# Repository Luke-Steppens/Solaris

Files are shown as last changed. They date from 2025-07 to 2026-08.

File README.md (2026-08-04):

This readme exists in its origional form from uni module COMP209 and will be edited down asap

# Solaris – Gesture-Controlled Interactive Light Sculpture

Solaris is a responsive, gesture-controlled light installation that uses real-time computer vision and robotic movement to create an interactive visual experience. Built for the COMP209 university group project, Solaris brings together elements of mechanical design, embedded systems, and computer vision. The system detects hand gestures and translates them into precise servo movements, allowing users to manipulate beams of light as they pass through rotating prisms and glass orbs.

---

## Project Overview
<p align="center">
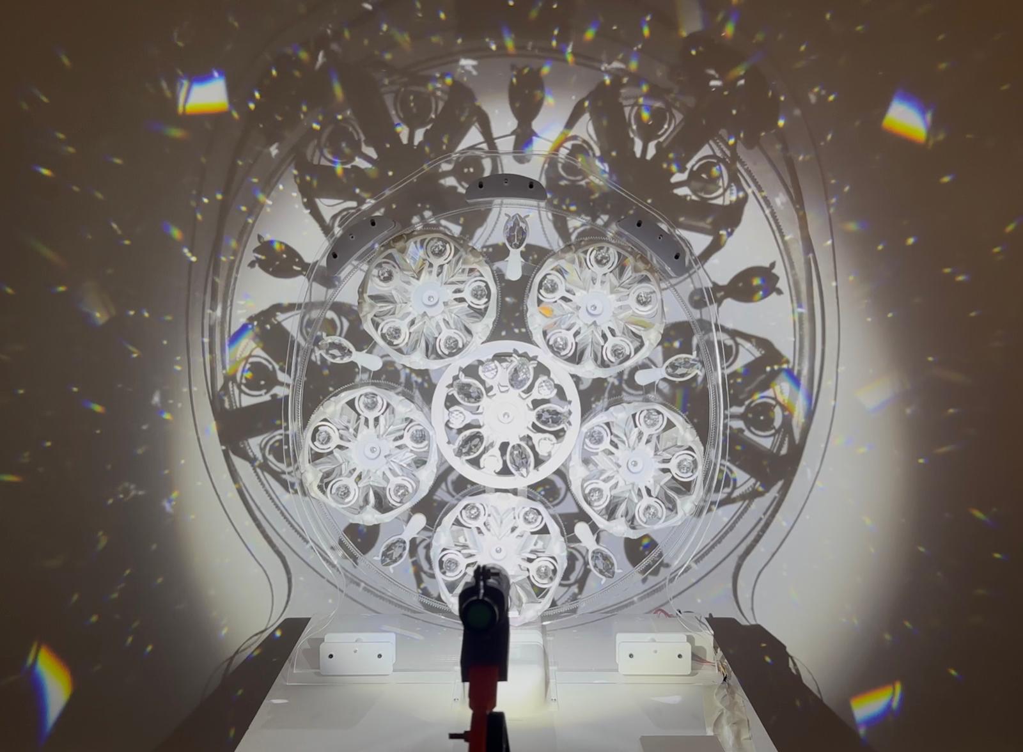
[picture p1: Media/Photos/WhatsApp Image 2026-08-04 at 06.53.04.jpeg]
  
</p>

<p align="center">
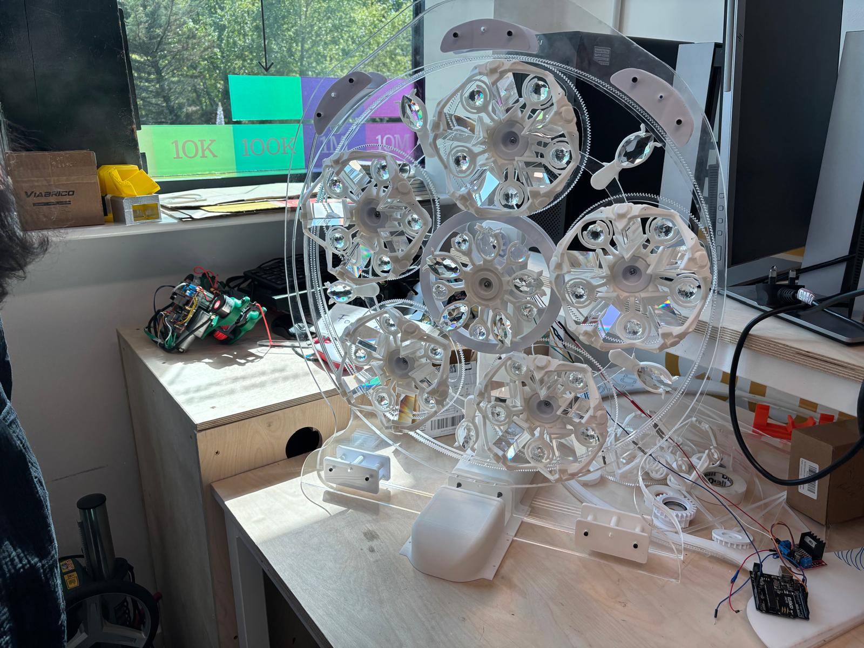
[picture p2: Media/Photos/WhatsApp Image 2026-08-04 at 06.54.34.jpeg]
  
</p>

Solaris enables users to interact with beams of light that refract through prisms and orbs, which are mechanically rotated by a robotic system in response to hand movements. The system leverages hand tracking, servo-controlled articulation, and custom-designed 3D-printed components to create a visually dynamic installation.

---

## Team Members and their development logs

<p align="center">
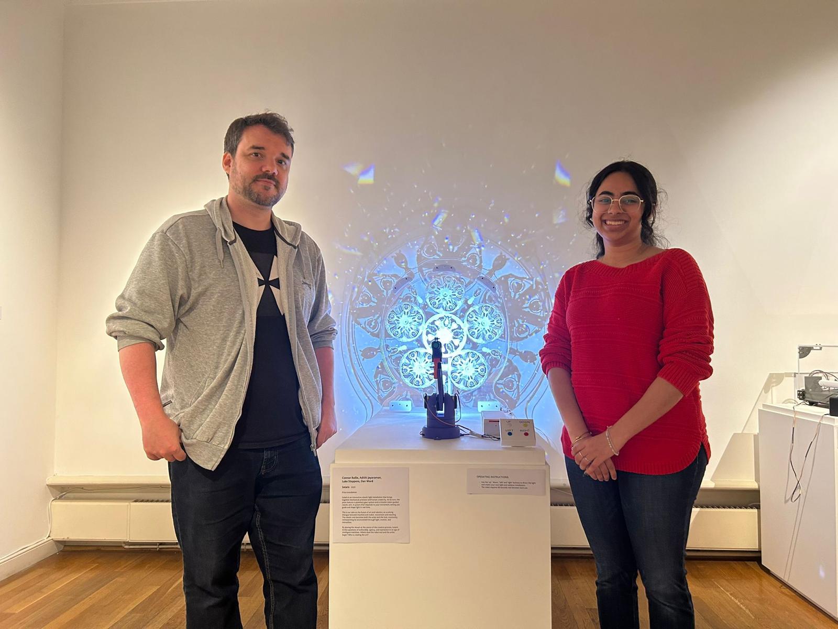
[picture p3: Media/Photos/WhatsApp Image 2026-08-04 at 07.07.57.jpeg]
  
</p>

- **Adithi Jayaraman** - https://www.notion.so/COMP209-1820f7ecc39f8019a431de44047871cf?pvs=4
- **Dan Ward** - https://www.notion.so/COMP209-Notes-Dan-19073cfe815b80a4bc4dd21392c3a36d
- **Conor Bailie** - https://www.notion.so/COMP209-191f1daf6e6e80539bbcf3f1b4c1cee5
- **Luke Steppens** - https://www.notion.so/COMP209-Robot-Design-60538fde323a44ef86ece4d31390ee01?pvs=4

---
## Individual Contribution

For this project I was the designer of the artefact. This included fabrication of parts and the construction of the device. 

Step 1

- Design and fabricate a miniature planetary gear system and motorise it
This test configuration allowed me to highlight potential future issues and assess suitability for the project.

MiniPrism v24again

<p align="center">
WhatsAppVideo2026-08-04at10 07 54-ezgif com-crop

---

Step 2

- Design primative glass mount
Creating this basic design highlighted future weight distribution concerns and glass mounting types to be attached to each planetary gear. The eventual mounts utilised the limited elasticity of PLA for an easy, secure friction fit. 
In the final piece, this part would be the hardest to finalise when went through many iterations.

<p align="center">
  
https://github.com/user-attachments/assets/e6f30164-5d48-40ff-9c3f-a2aaa589af57

---

Step 3
- Planetary gear and housing
This main housing needed to contain all gearing elements and keep balance whilst over 2KG of glass rotated within it.

<p align="center">
WhatsApp Image 2026-08-04 at 10 32 14

---

Final Design

https://github.com/user-attachments/assets/c0ae6e90-3917-4fb3-a8e9-6cd88678b772

---

<p align="center">
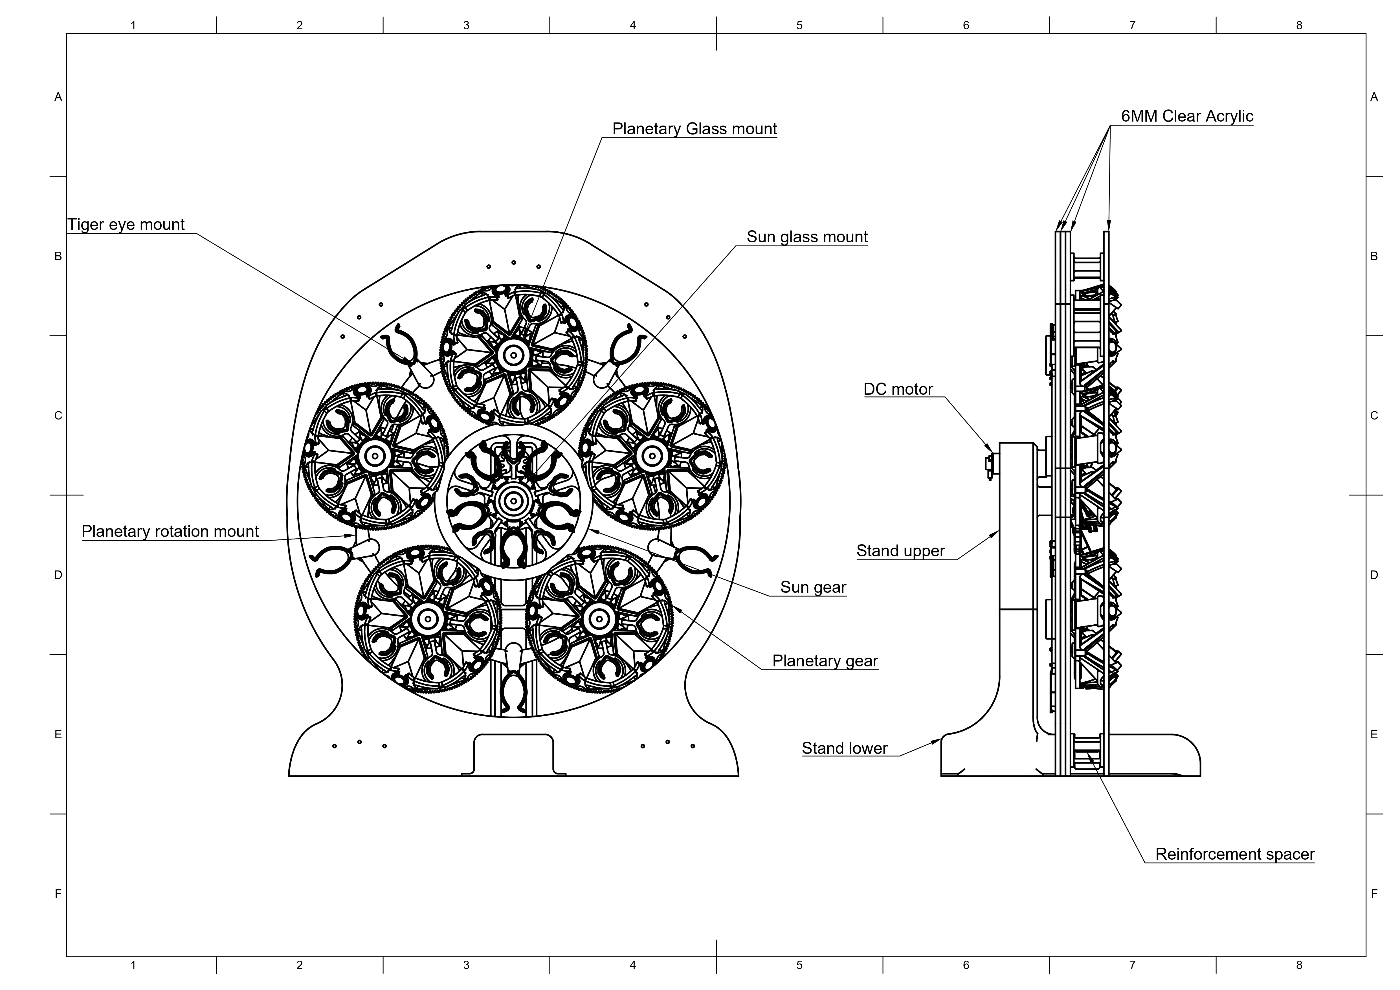
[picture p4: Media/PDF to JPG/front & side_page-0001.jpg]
  
</p>

<p align="center">
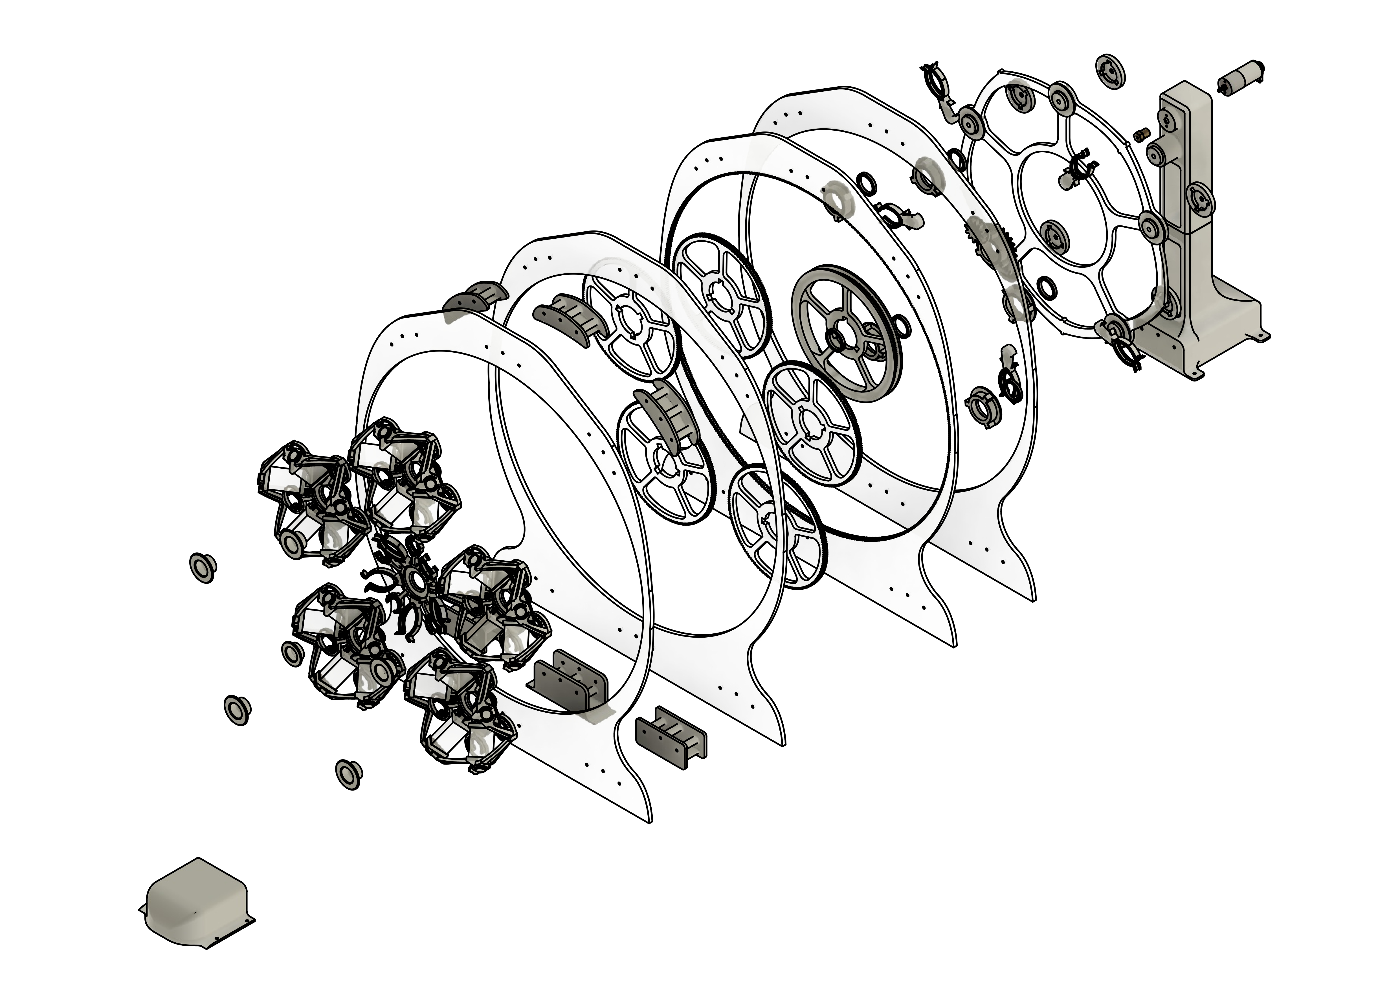
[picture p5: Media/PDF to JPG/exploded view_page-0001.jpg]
  
</p>

---
## Core Features

| Feature | Technology Stack |
|---|---|
| **Gesture Detection** | OpenCV & MediaPipe |
| **Robotic Control** | Arduino Uno + Servos (3 DOF robotic arm) |
| **Inverse Kinematics** | Custom Python logic using Law of Cosines & atan2 |
| **Standalone Execution** | Raspberry Pi 3B with auto-executing hand tracking |
| **Prism Control Mechanism**| Custom 3D-printed planetary gear system |

---

## Repository Structure

```

.
├── CAD/                  # Mechanical component designs
├── Code/
│   ├── Final\_Script/     # Final working Python & Arduino scripts
│   └── Draft/            # Archived experimental code
├── Documentation/        # Technical notes, setup guides, sprint logs
├── Electronics/          
├── Media/                # Photos, renders, and demo videos
├── LICENSE
└── README.md             # This file

```

---

## Hardware Architecture

---

| **Component** | **Role & Function** |
| --- | --- |
| **Raspberry Pi 3B** | Main processing unit: captures webcam input, runs hand-tracking algorithms, and sends servo commands via serial. |
| **USB Webcam** | Captures real-time hand movements for gesture recognition using OpenCV and MediaPipe. |
| **Arduino Uno** | Interprets serial commands from the Raspberry Pi and controls servo motors accordingly. |
| **Raspberry Pi Pico** (early prototype) | Initially tested for direct servo control during the development phase. |
| **3-DOF Robotic Arm** | Mechanically moves and positions optical elements based on hand gestures. |
| **Glass Prisms & Orbs** | Optical components that bend, reflect, and scatter light, producing dynamic visual effects. |

---

## CAD & Mechanical Prototyping

The physical mounts were designed to hold glass orbs and prisms, with a focus on durability and smooth interaction. The final setup uses a large planetary gear system with precise gear ratios and bearing mounts.

### Prototype Timeline

#### Prototype 1: Basic Rotating Mount
- Single glass mount on a vertical shaft with bearings.
- Confirmed basic concept but suffered from poor front-weight balance.

#### Prototype 1.2: Motorised Gear Proof
- Implemented a miniature planetary gear system.
- Powered by a 3–6V DC motor via L298N H-Bridge, controlled by Arduino Uno.
- Proved gear logic and embedded housing feasibility.

#### Prototype 2: Modular Snap-Fit Design
- Reinforced spokes and improved gear tolerance.
- Orbs held via friction; prisms mounted with snap-fit.
- Reduced breakage and improved part interchangeability.

#### Final Model: Solaris Gear System
- Over 65 cm tall, featuring:
  - 3× gears (175 teeth each)
  - Outer ring gear with 525 teeth
  - Bearings and composite joints for smooth motion
- Most complex assembly; precision-critical design required iterative CAD planning.

---

## Software Pipeline

### Hand Tracking
- **MediaPipe + OpenCV**: Captures 21 hand landmarks in real time.
- Index finger (landmark 8) is used for positional tracking on the screen.
- Coordinate smoothing and Z-depth estimation included for improved accuracy.

### Arduino Communication
- Python script on Raspberry Pi sends joint angles over serial.
- Arduino Uno decodes values and adjusts servos via `Servo.h`.

---

## System Iterations

### Phase 1: Laptop-based Tracking
- Python script captured webcam feed on laptop.
- Angles computed locally and sent via serial.
- Used for validating tracking accuracy and angle mapping.

### Phase 2: ESP32-CAM
- Attempted to offload webcam + computation.
- Issues:
  - Long boot-up time
  - WiFi-dependent video feed caused jitter
  - Abandoned for real-time stability concerns

### Final Phase: Raspberry Pi 3B
- Full autonomy achieved with USB webcam and local computation.
- Auto-runs on boot via `.bashrc` and virtualenv.
- Sends data directly to Arduino Uno via `/dev/ttyUSB0`.
- Torch holder added to robotic arm for controlled light emission.

---

## Final Installation

- Mounted vertically in a dark space to emphasize light patterns.
- Gestures cause light to move and refract through prisms in real-time.
- Entire system is **plug-and-play**, no additional setup required:
  - No internet
  - No monitor
  - No manual pip installs or environment activation

---

## License

Licensed under the [Apache License 2.0](LICENSE). Free for educational and non-commercial use.

---

## Media & Demo

Demo footage and final installation images can be found in the [`Media/`](./Media/) folder.

---

## How to Run (Summary)

1. Power on Raspberry Pi 3B
2. Turn on the 12v barrty power 
3. System auto-launches hand tracking via `.bashrc`
4. Webcam captures hand motion
5. Raspberry Pi calculates joint angles
6. Angles sent to Arduino via serial
7. Arduino adjusts robotic arm and prism mount accordingly

```

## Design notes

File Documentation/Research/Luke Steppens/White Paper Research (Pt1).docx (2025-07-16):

White Papers

This section covers the beginning research into the topics of Light with regard to prisms and Machine vision and object tracking.

[1]

R. G. Kuehni, Color: An Introduction to Practice and Principles. Newark, UNITED STATES: John Wiley & Sons, Incorporated, 2012. Accessed: Feb. 01, 2025. [Online]. Available: http://ebookcentral.proquest.com/lib/falmouth-ebooks/detail.action?docID=1031869

[2]

X. Cui, H. Fan, H. Chen, S. Chen, Y. Zhao, and K. Lim, “Epipolar geometry for prism-based single-lens stereovision,” Machine Vision and Applications, vol. 28, no. 3–4, pp. 313–326, May 2017, doi: 10.1007/s00138-017-0822-x (https://doi.org/10.1007/s00138-017-0822-x).

[3]

K. K. Sharma, Optics: Principles and Applications. Chantilly, UNITED STATES: Elsevier Science & Technology, 2006. Accessed: Feb. 01, 2025. [Online]. Available: http://ebookcentral.proquest.com/lib/falmouth-ebooks/detail.action?docID=274237

[4]

A. Moksyakov, Y. Wu, S. A. Gadsden, J. Yawney, and M. AlShabi, “Object Detection and Tracking with YOLO and the Sliding Innovation Filter,” Sensors (Basel, Switzerland), vol. 24, no. 7, pp. 2107-, 2024, doi: 10.3390/s24072107 (https://doi.org/10.3390/s24072107).

[5]

M. Born and E. Wolf, Principles of Optics: Electromagnetic Theory of Propagation, Interference and Diffraction of Light. Chantilly, UNITED KINGDOM: Elsevier Science & Technology, 1980. Accessed: Feb. 01, 2025. [Online]. Available: http://ebookcentral.proquest.com/lib/falmouth-ebooks/detail.action?docID=4586942

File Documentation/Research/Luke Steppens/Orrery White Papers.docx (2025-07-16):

Orrey Research White Papers

[1]

L. Xiang, N. Gao, and A. Hu, “Dynamic analysis of a planetary gear system with multiple nonlinear parameters,” Journal of Computational and Applied Mathematics, vol. 327, pp. 325–340, Jan. 2018, doi: 10.1016/j.cam.2017.06.021 (https://doi.org/10.1016/j.cam.2017.06.021).

[2]

T. Freeth, “Building the Cosmos in the Antikythera Mechanism,” in Proceedings of From Antikythera to the Square Kilometre Array: Lessons from the Ancients — PoS(Antikythera & SKA), Kerastari, Greece: Sissa Medialab, Mar. 2013, p. 018. doi: 10.22323/1.170.0018 (https://doi.org/10.22323/1.170.0018).

[3]

B. M. Naperkoski, “EXPLORING THE DYNAMICS OF A MECHANICAL WATCH LEVER ESCAPEMENT USING FINITE ELEMENT ANALYSIS”.

[4]

M. Whiting, “Orrery Developments: The Use of Meccano in Constructing Planetaria,” no. 94, 2007.

[5]

T. Buick, Orrery: A Story of Mechanical Solar Systems, Clocks, and English Nobility. Springer Science & Business Media, 2013.

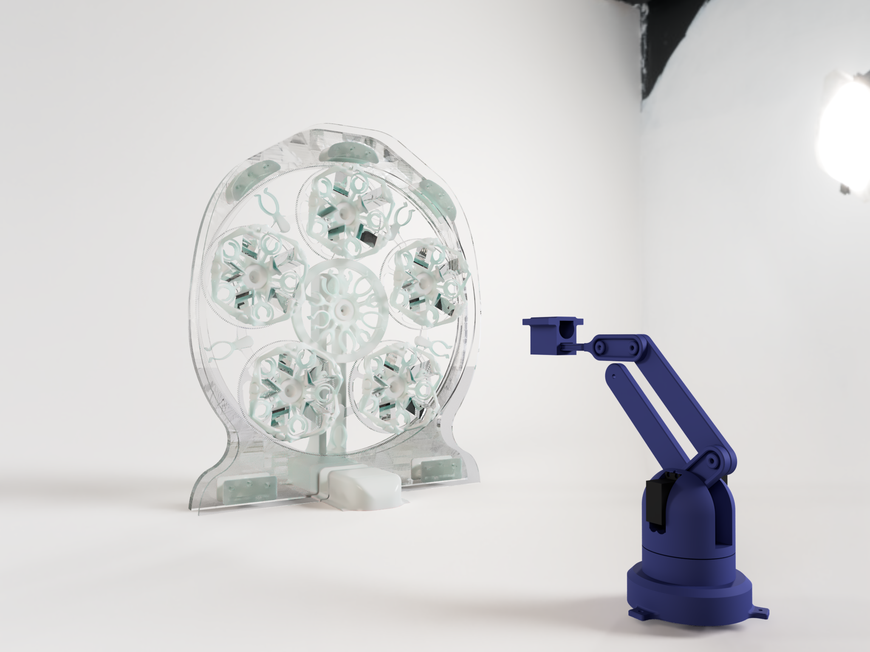
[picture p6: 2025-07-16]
CAD/Renders/Arm_Solaris_2025-May-12_12-01-38PM-000_CustomizedView1214748056.png

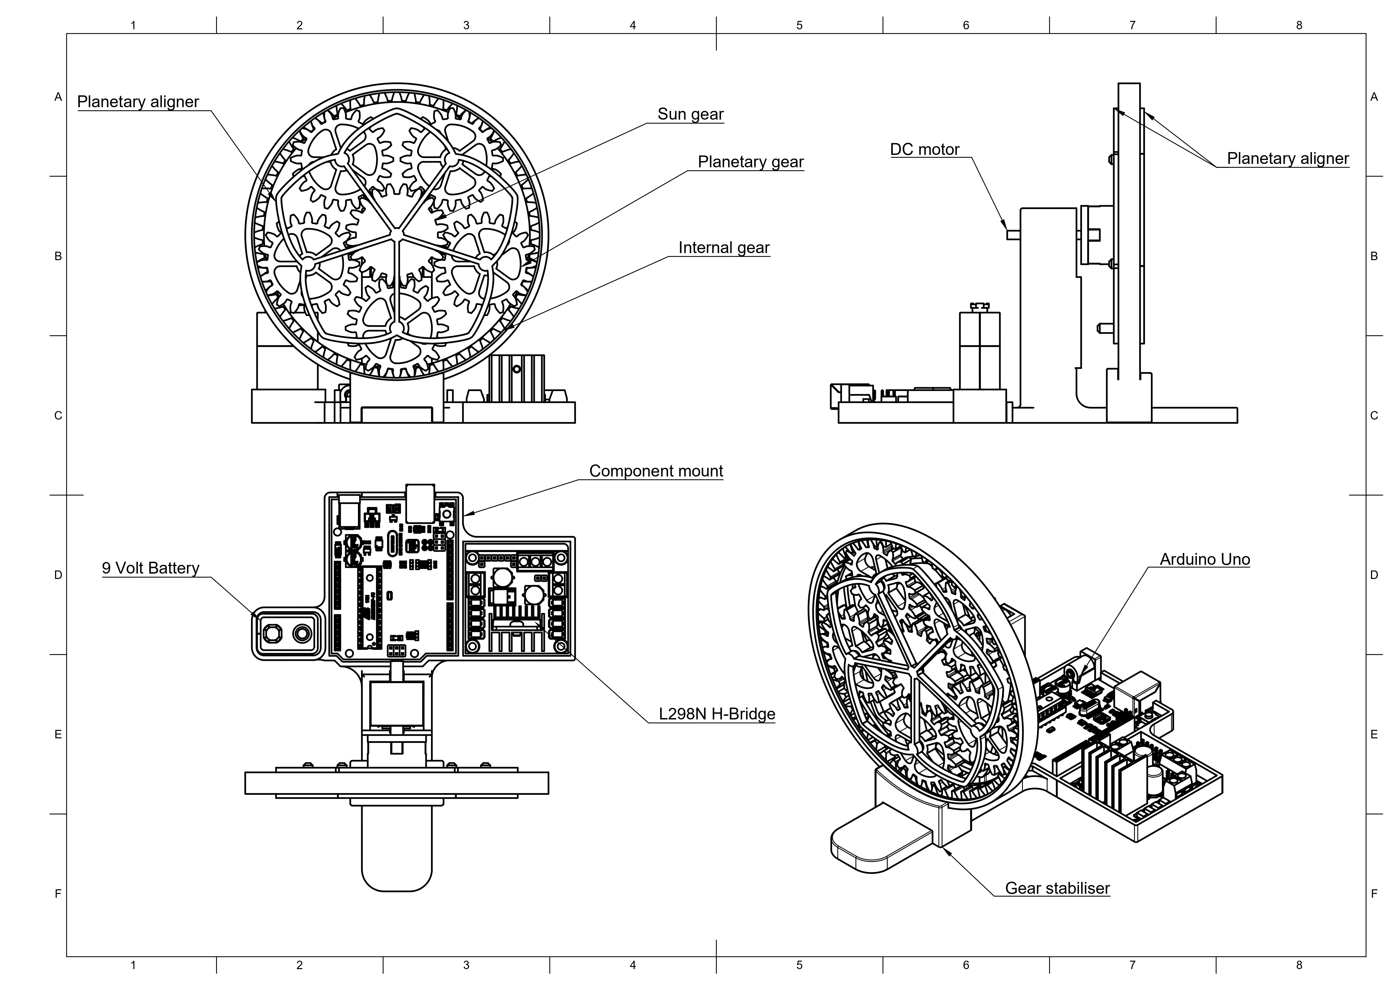
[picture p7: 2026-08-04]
Media/PDF to JPG/minidrawing_page-0001.jpg

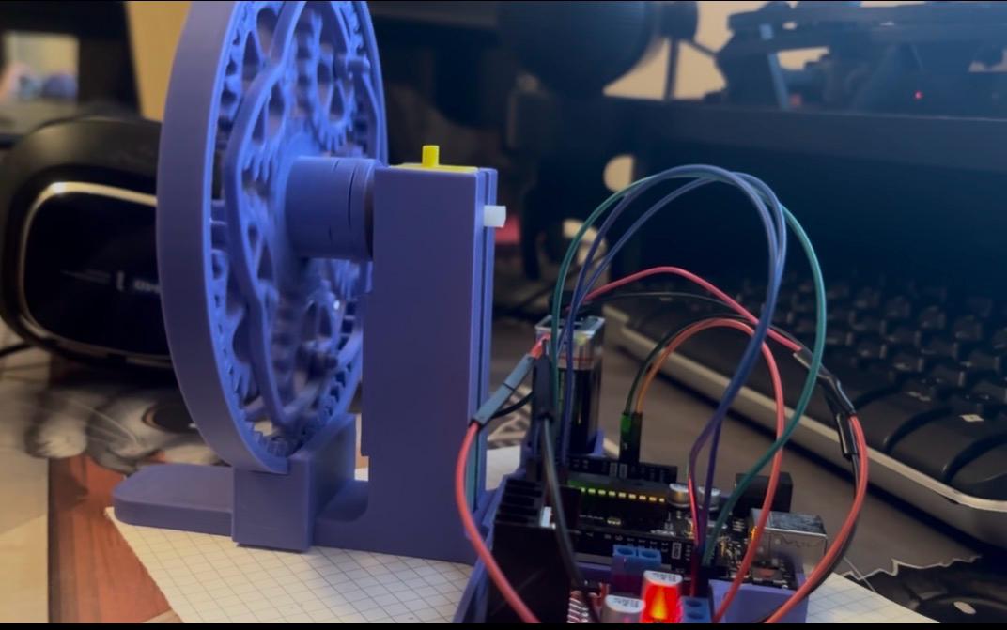
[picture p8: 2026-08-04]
Media/Photos/mini1 (3).jpeg

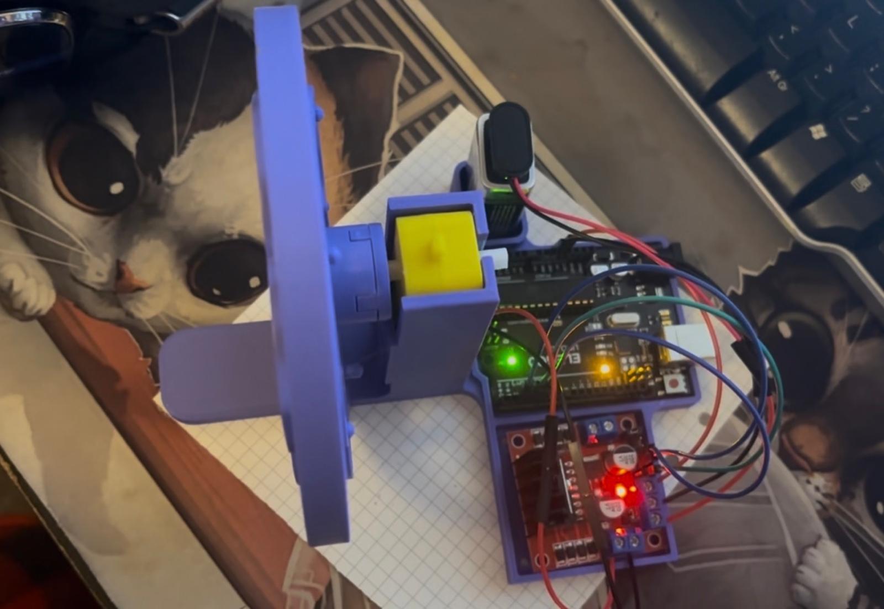
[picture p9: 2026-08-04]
Media/Photos/mini1 (4).jpeg

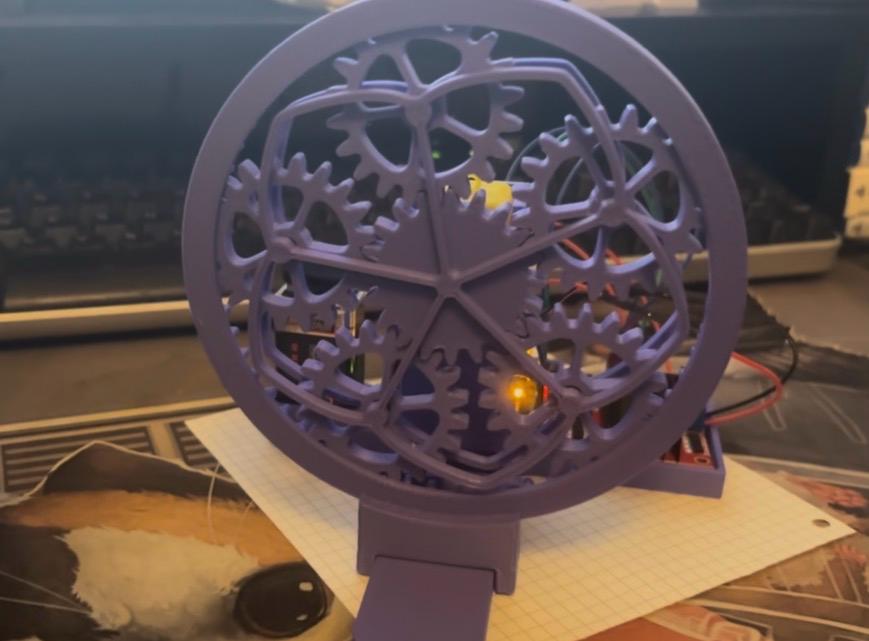
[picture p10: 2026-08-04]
Media/Photos/mini1 (1).jpeg

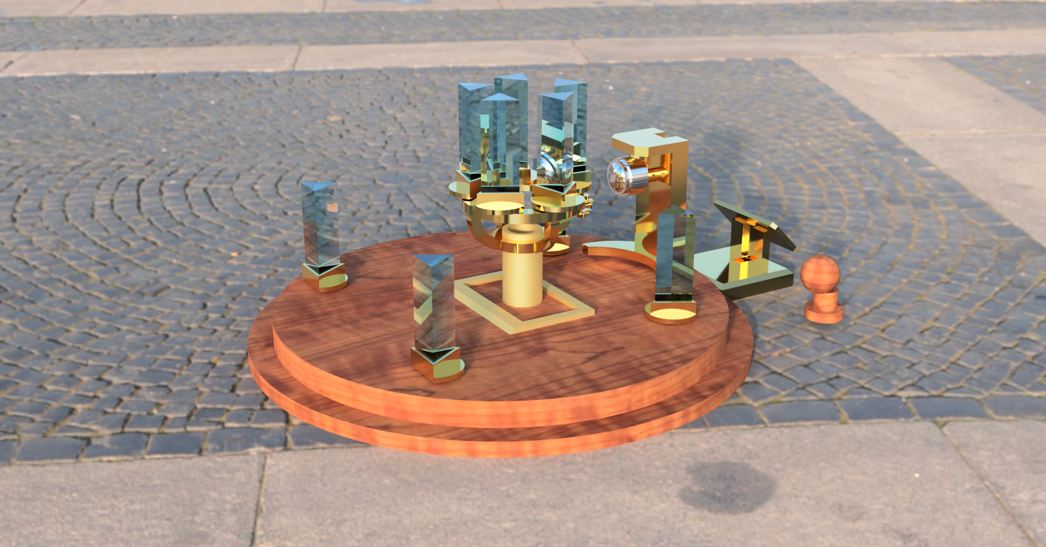
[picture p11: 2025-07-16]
CAD/Renders/Untitled_v1_2025-Feb-19_03-12-44PM-000_CustomizedView29410108841 (1).png

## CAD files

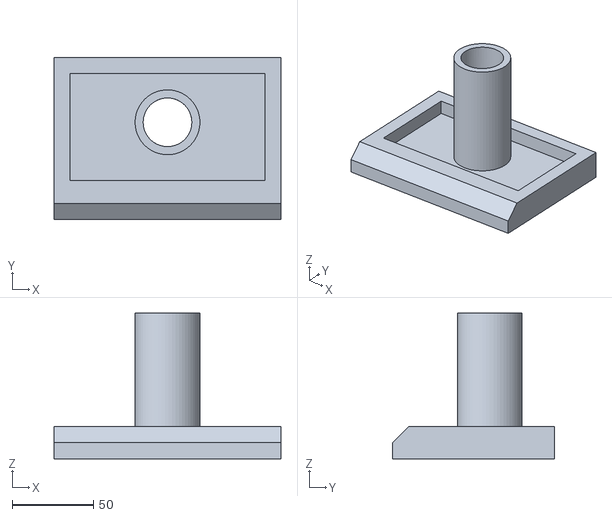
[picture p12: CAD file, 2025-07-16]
CAD/Draft Models/prism-lobe_Component1 v1.stl
140.0 x 100.0 x 90.0

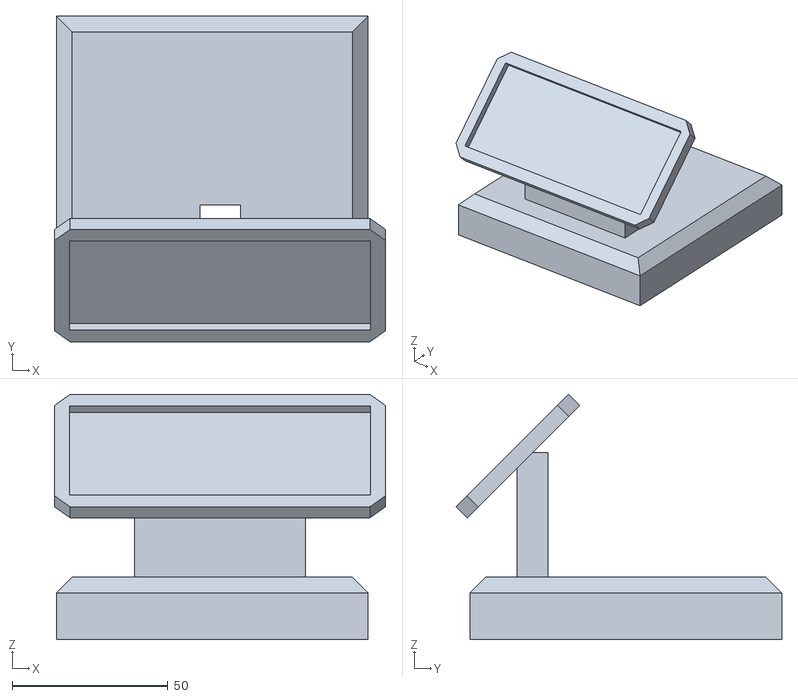
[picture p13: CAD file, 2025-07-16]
CAD/Draft Models/base v2.stl
106.2 x 104.5 x 78.7

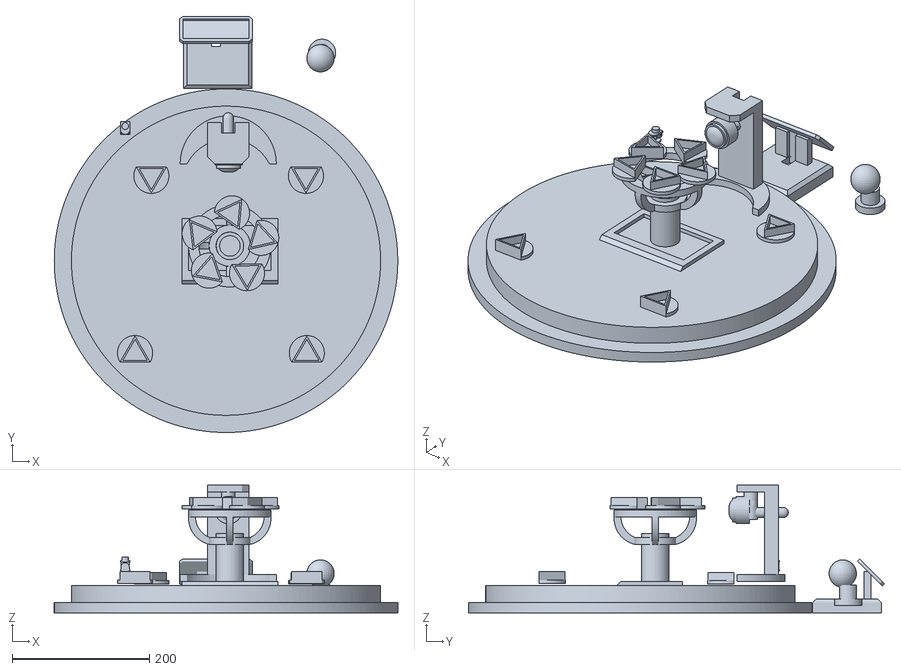
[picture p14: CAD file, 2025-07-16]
CAD/Draft Models/draft v3.stl
499.9 x 605.4 x 186.1

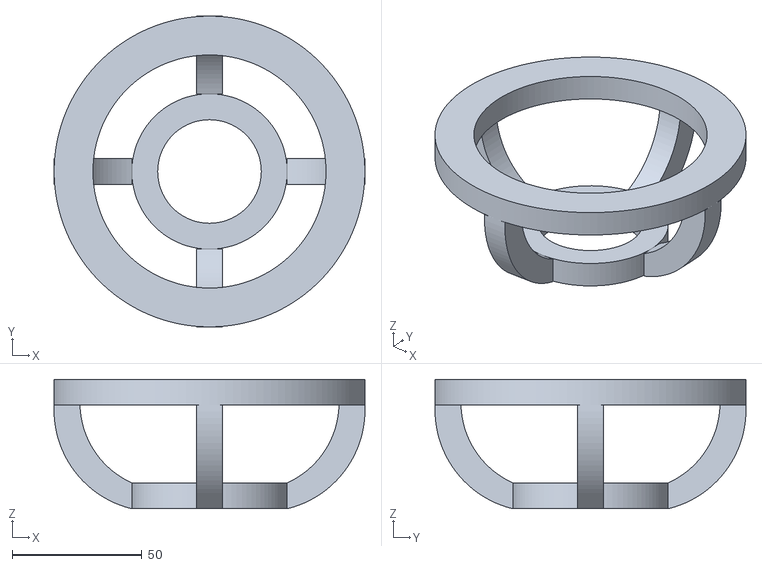
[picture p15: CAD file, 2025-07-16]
CAD/Draft Models/roundabout v2.stl
120.1 x 120.1 x 50.0

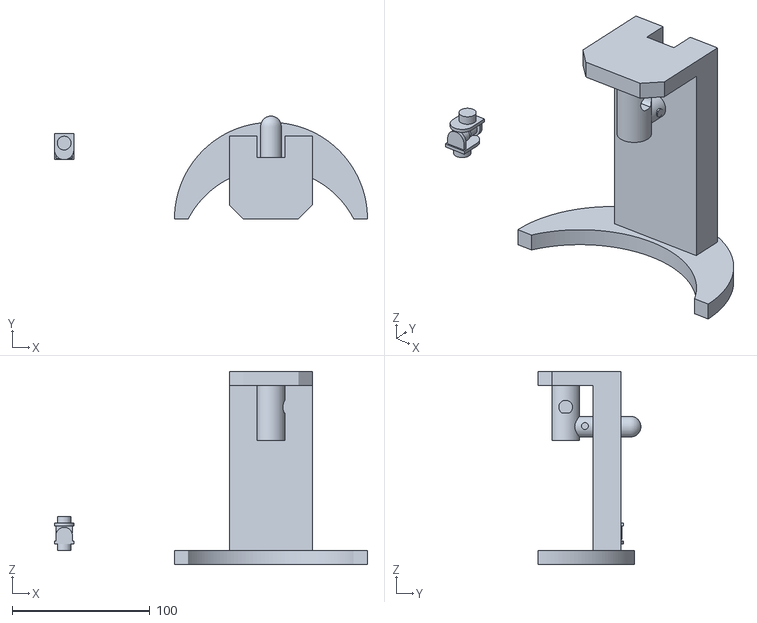
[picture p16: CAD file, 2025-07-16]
CAD/Draft Models/comp209 light mount v6.stl
227.0 x 74.6 x 140.0

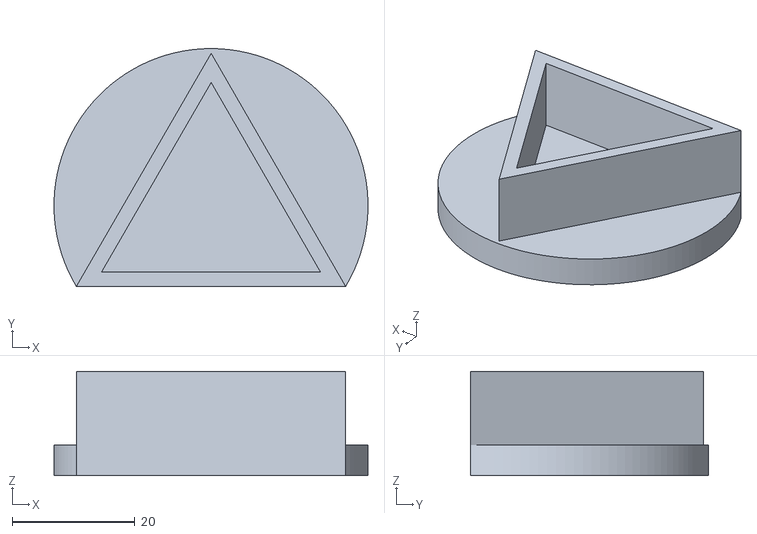
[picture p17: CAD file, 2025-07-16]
CAD/Draft Models/prism_Component1 v3.stl
51.1 x 38.7 x 17.0

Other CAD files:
CAD/Assemblies/Flashlight Mount & Arm/Flashlight Mount.f3d
CAD/Assemblies/Flashlight Mount & Arm/FlashlightMountAndArmFinal.f3d
CAD/Assemblies/Flashlight Mount & Arm/FlashlightMountPrototype4.f3d
CAD/Assemblies/Flashlight Mount & Arm/FlashlightRingSmall 2.f3d
CAD/Assemblies/Flashlight Mount & Arm/FlashlightRingSmallDouble 3.f3d
CAD/Assemblies/Planetary Concept/Planetary Concept v1.f3z
CAD/Assemblies/Planetary Gear Artefact (Final)/Solaris.f3z
CAD/Assemblies/Prototypes/MiniPrism Prototype.f3z
CAD/Draft Models/base v2.f3d
CAD/Draft Models/comp209 light mount v6.f3d
CAD/Draft Models/draft v3.f3z
CAD/Draft Models/prism-lobe_Component1 v1.f3d
CAD/Draft Models/prism_Component1 v3.f3d
CAD/Draft Models/round prism v1.f3d
CAD/Draft Models/roundabout v2.f3d
CAD/Laser Cutting Sketches/Back Piece and Main Teeth Ring v1.f3d
CAD/Laser Cutting Sketches/Outer Ring (No Teeth) 1x Planet 1x Sun v1.f3d
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

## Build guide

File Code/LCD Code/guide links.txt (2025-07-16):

for this code I installed circuitpython onto a pi pico and programmed it with thonny

libraries vid for pico and screen
https://www.youtube.com/watch?v=KaGHxvVnKQ4

https://thonny.org/

I watched this tutorial for this
https://www.youtube.com/watch?v=QUOhSPpJfOI&t=153s

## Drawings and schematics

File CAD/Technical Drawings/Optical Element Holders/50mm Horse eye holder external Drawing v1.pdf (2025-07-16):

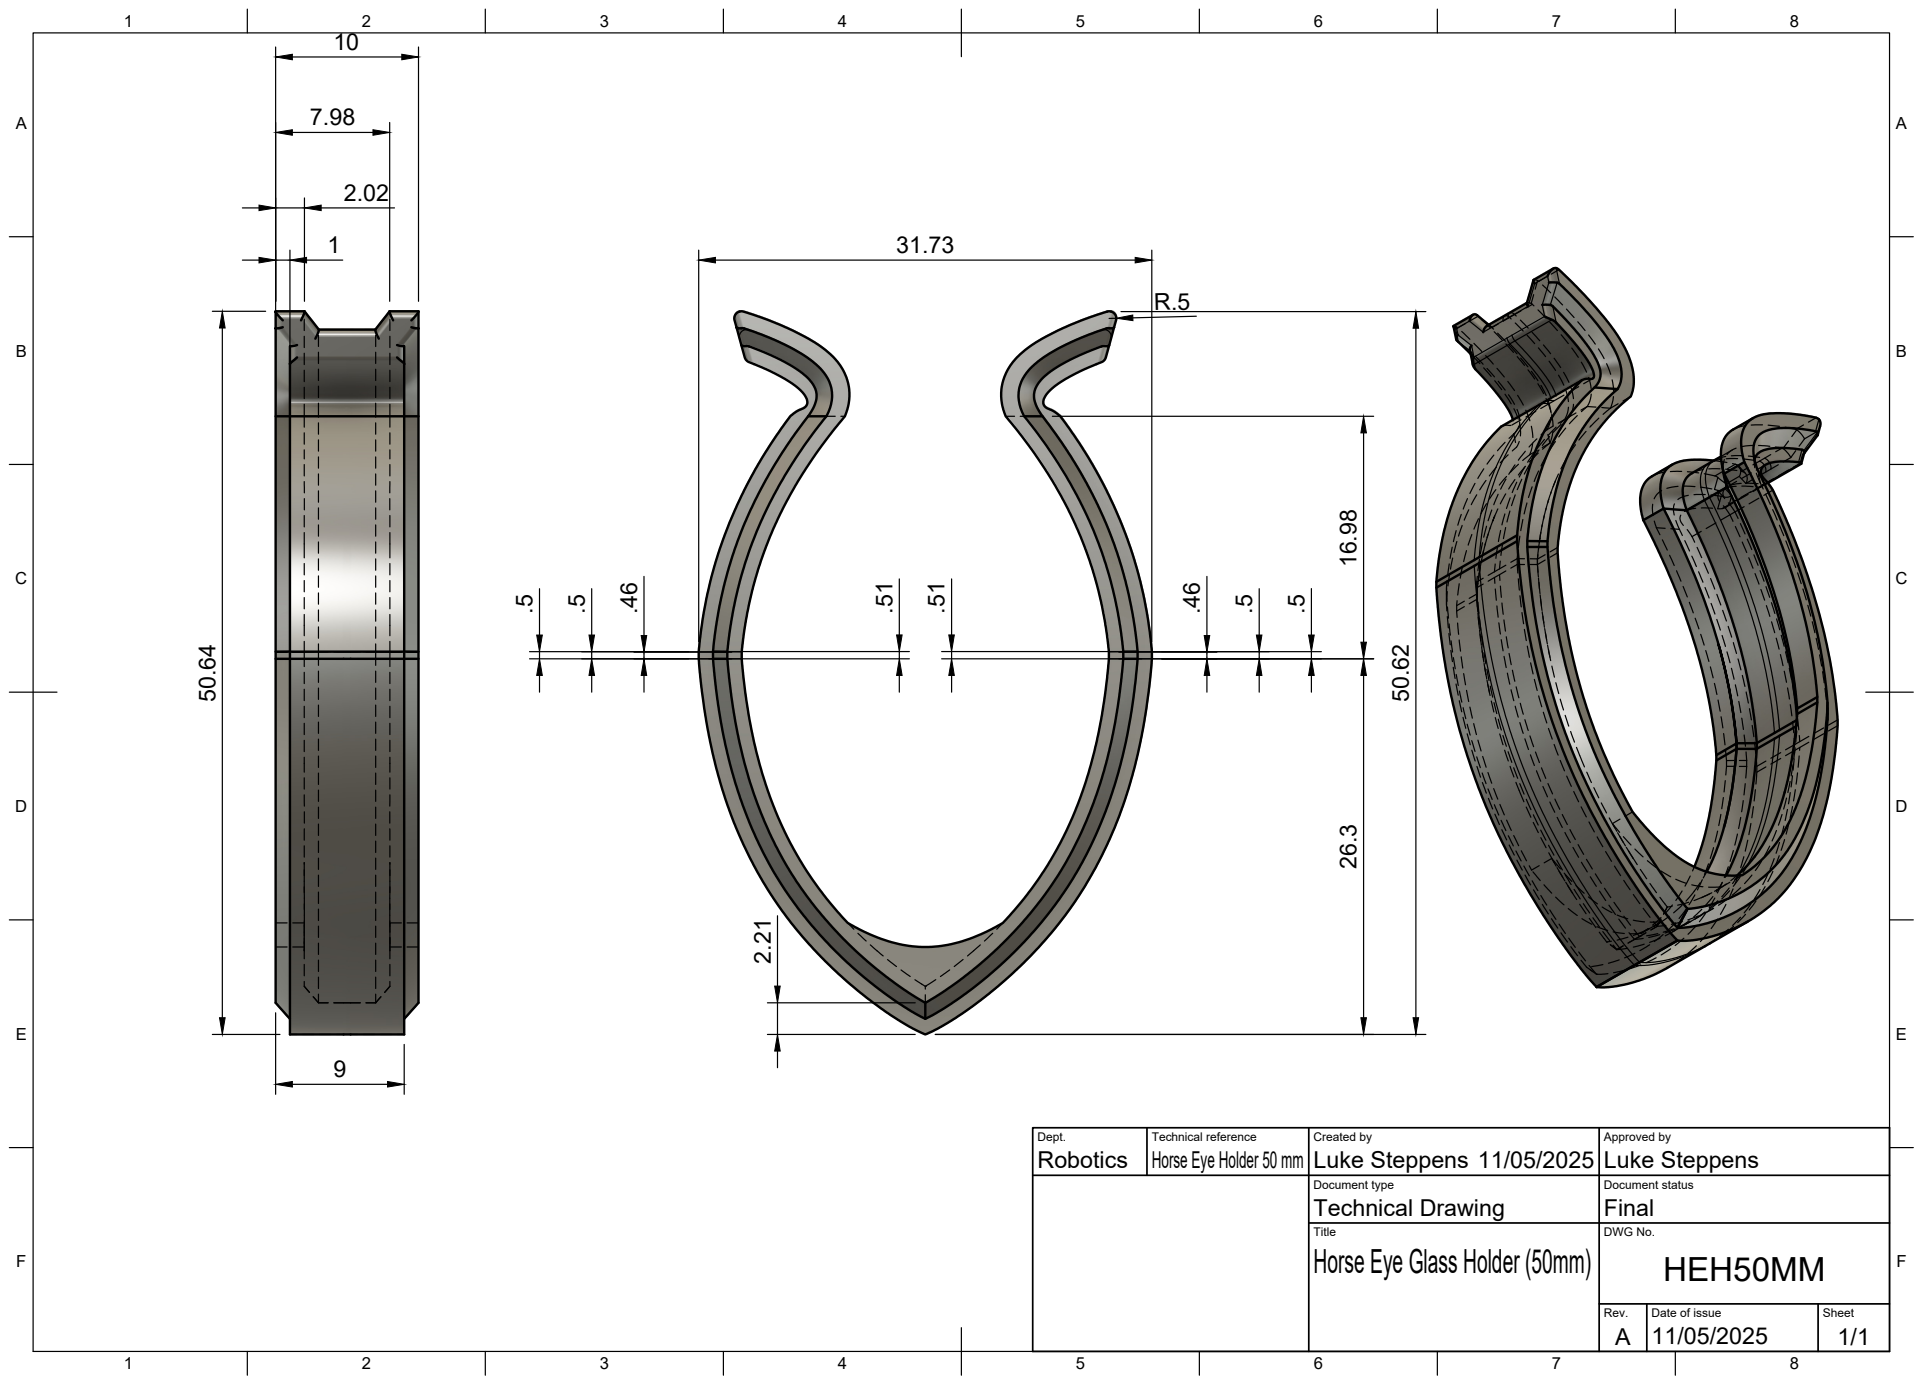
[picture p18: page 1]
Title; DWG No.; Rev.; Date of issue; Sheet; Horse Eye Glass Holder (50mm); HEH50MM

Dept. Robotics | Technical reference Horse Eye Holder 50 mm | Created by Luke Steppens 11/05/2025 | Approved by Luke Steppens

Document type Technical Drawing | Document status Final

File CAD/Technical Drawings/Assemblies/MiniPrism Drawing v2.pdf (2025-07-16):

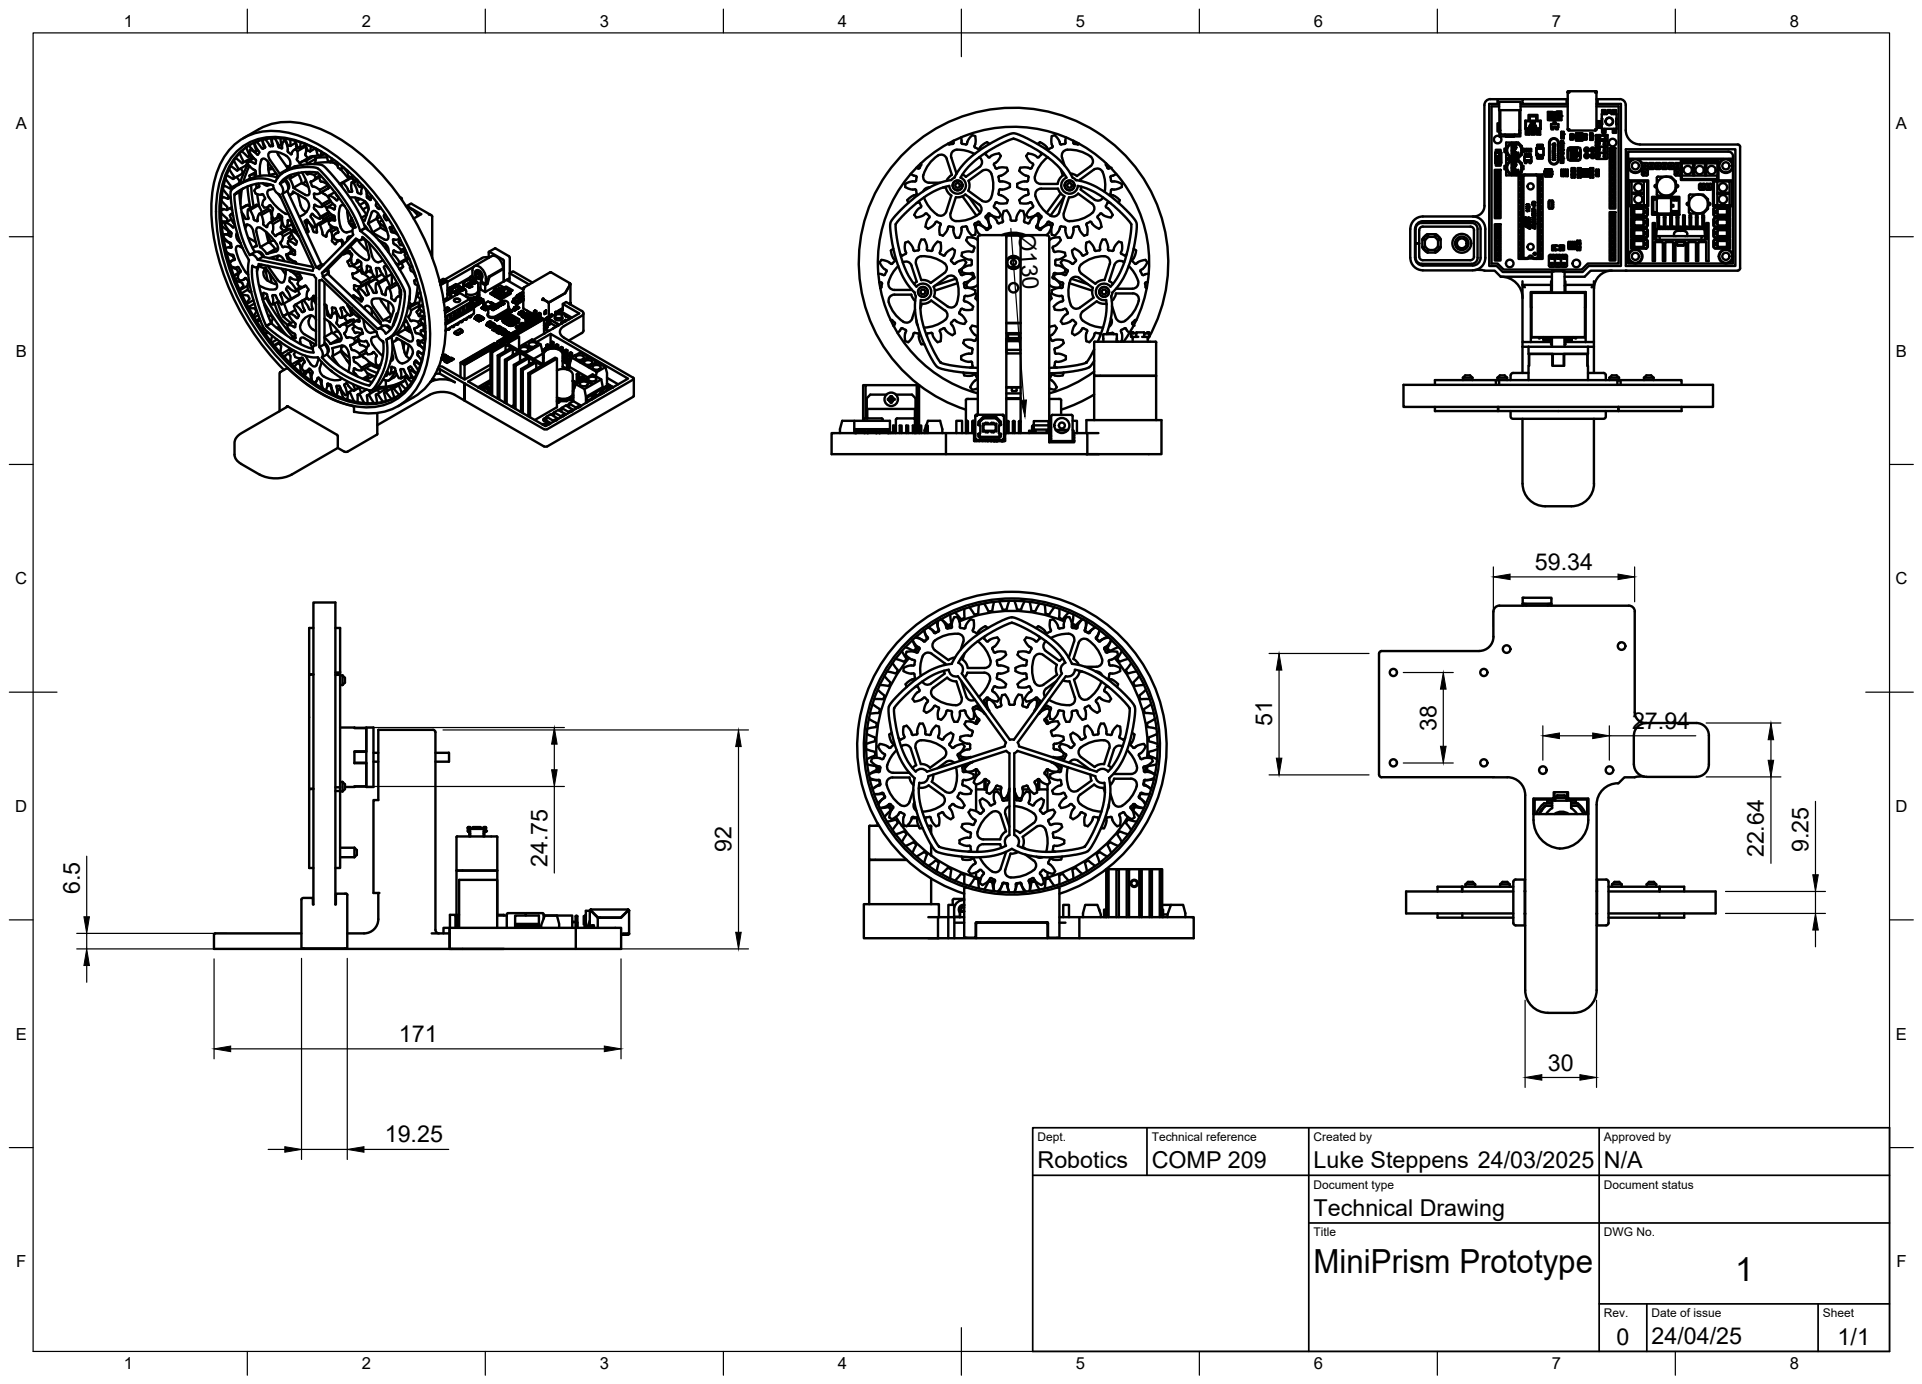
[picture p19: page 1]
Dept.; Technical reference; Created by; Approved by; Document type; Document status; Title; DWG No.; Rev.; Date of issue; Sheet; Technical Drawing; MiniPrism Prototype; Robotics COMP 209; Luke Steppens

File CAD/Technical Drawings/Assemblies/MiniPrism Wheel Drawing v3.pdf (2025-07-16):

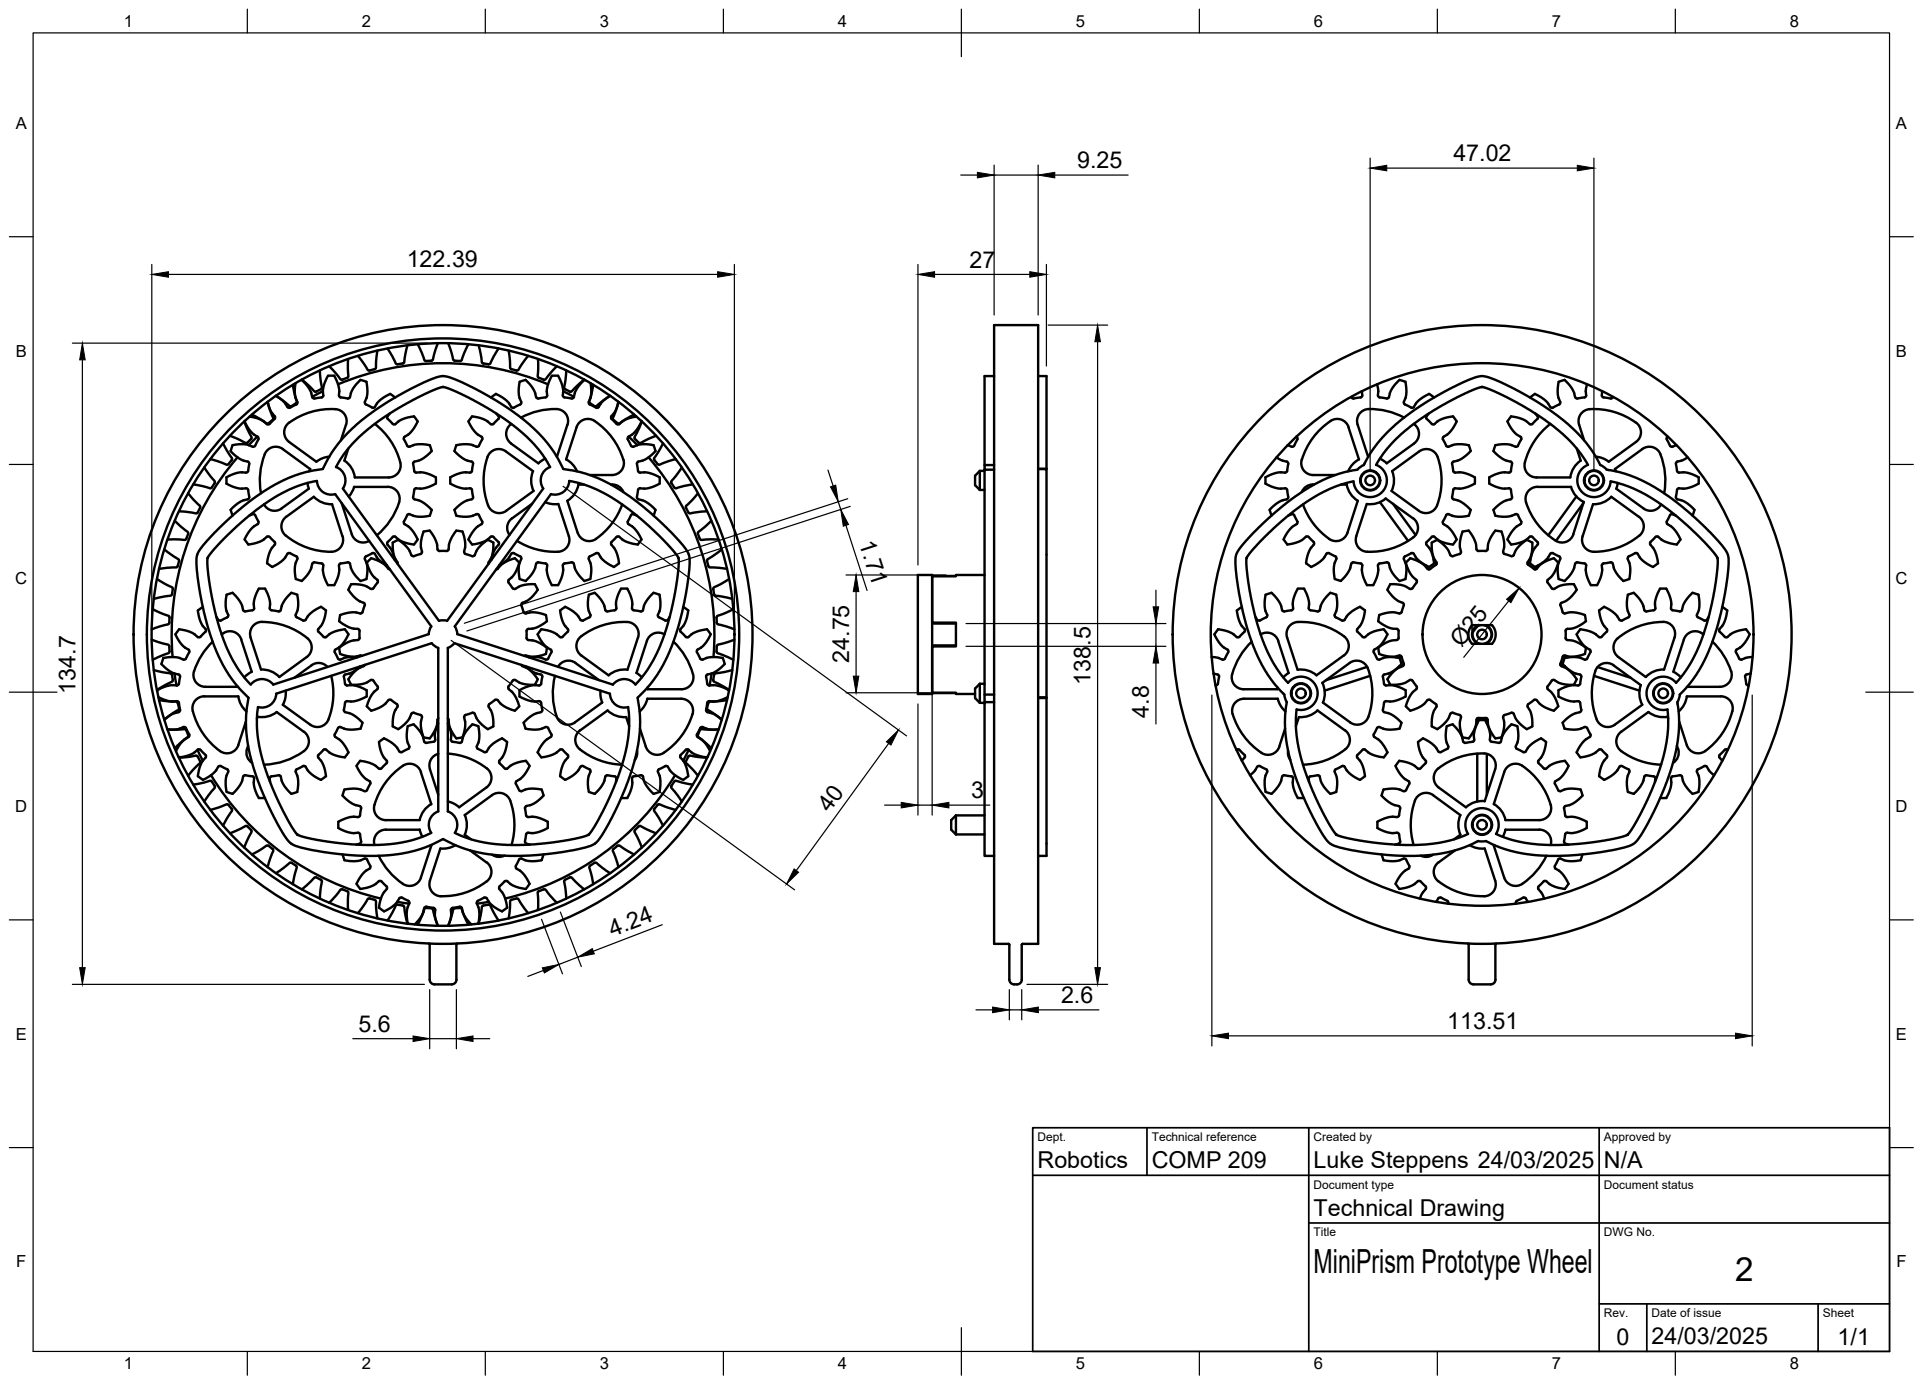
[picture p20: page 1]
Title; DWG No.; Rev.; Date of issue; Sheet; MiniPrism Prototype Wheel

Dept. Robotics | Technical reference COMP 209 | Created by Luke Steppens 24/03/2025 | Approved by N/A

Document type Technical Drawing | Document status

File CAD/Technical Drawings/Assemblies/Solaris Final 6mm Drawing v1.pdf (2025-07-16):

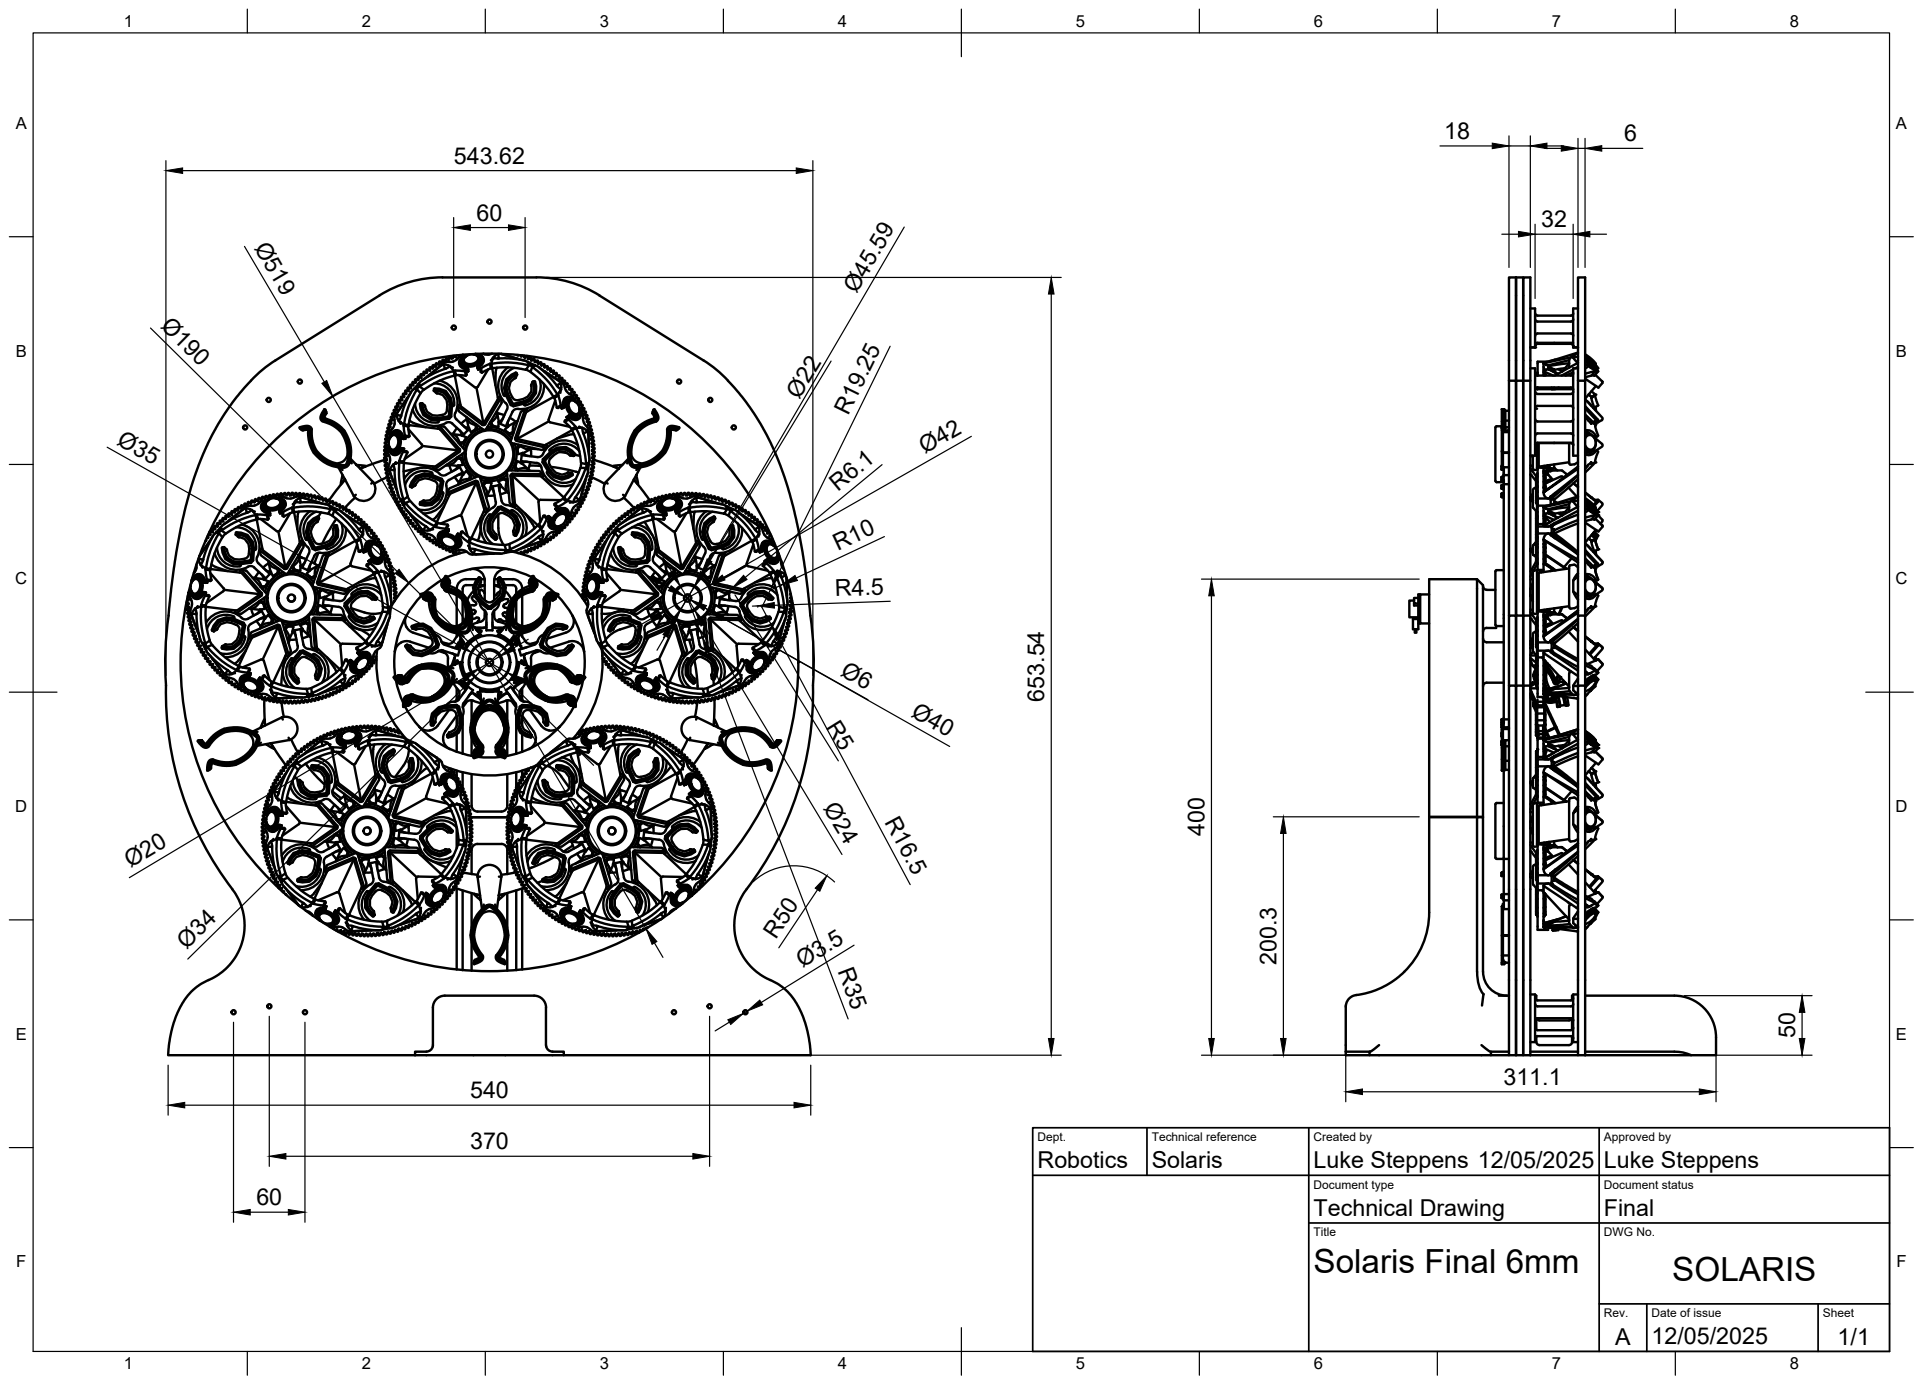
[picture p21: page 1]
8 BCDEF; ABCDEF; Dept.; Technical reference; Created by; Approved by; Document type; Document status; Title; DWG No.; Rev.; Date of issue; Sheet A 12/05/2025; Technical Drawing; Final; Solaris Final 6mm; SOLARIS; Robotics Solaris; Luke Steppens

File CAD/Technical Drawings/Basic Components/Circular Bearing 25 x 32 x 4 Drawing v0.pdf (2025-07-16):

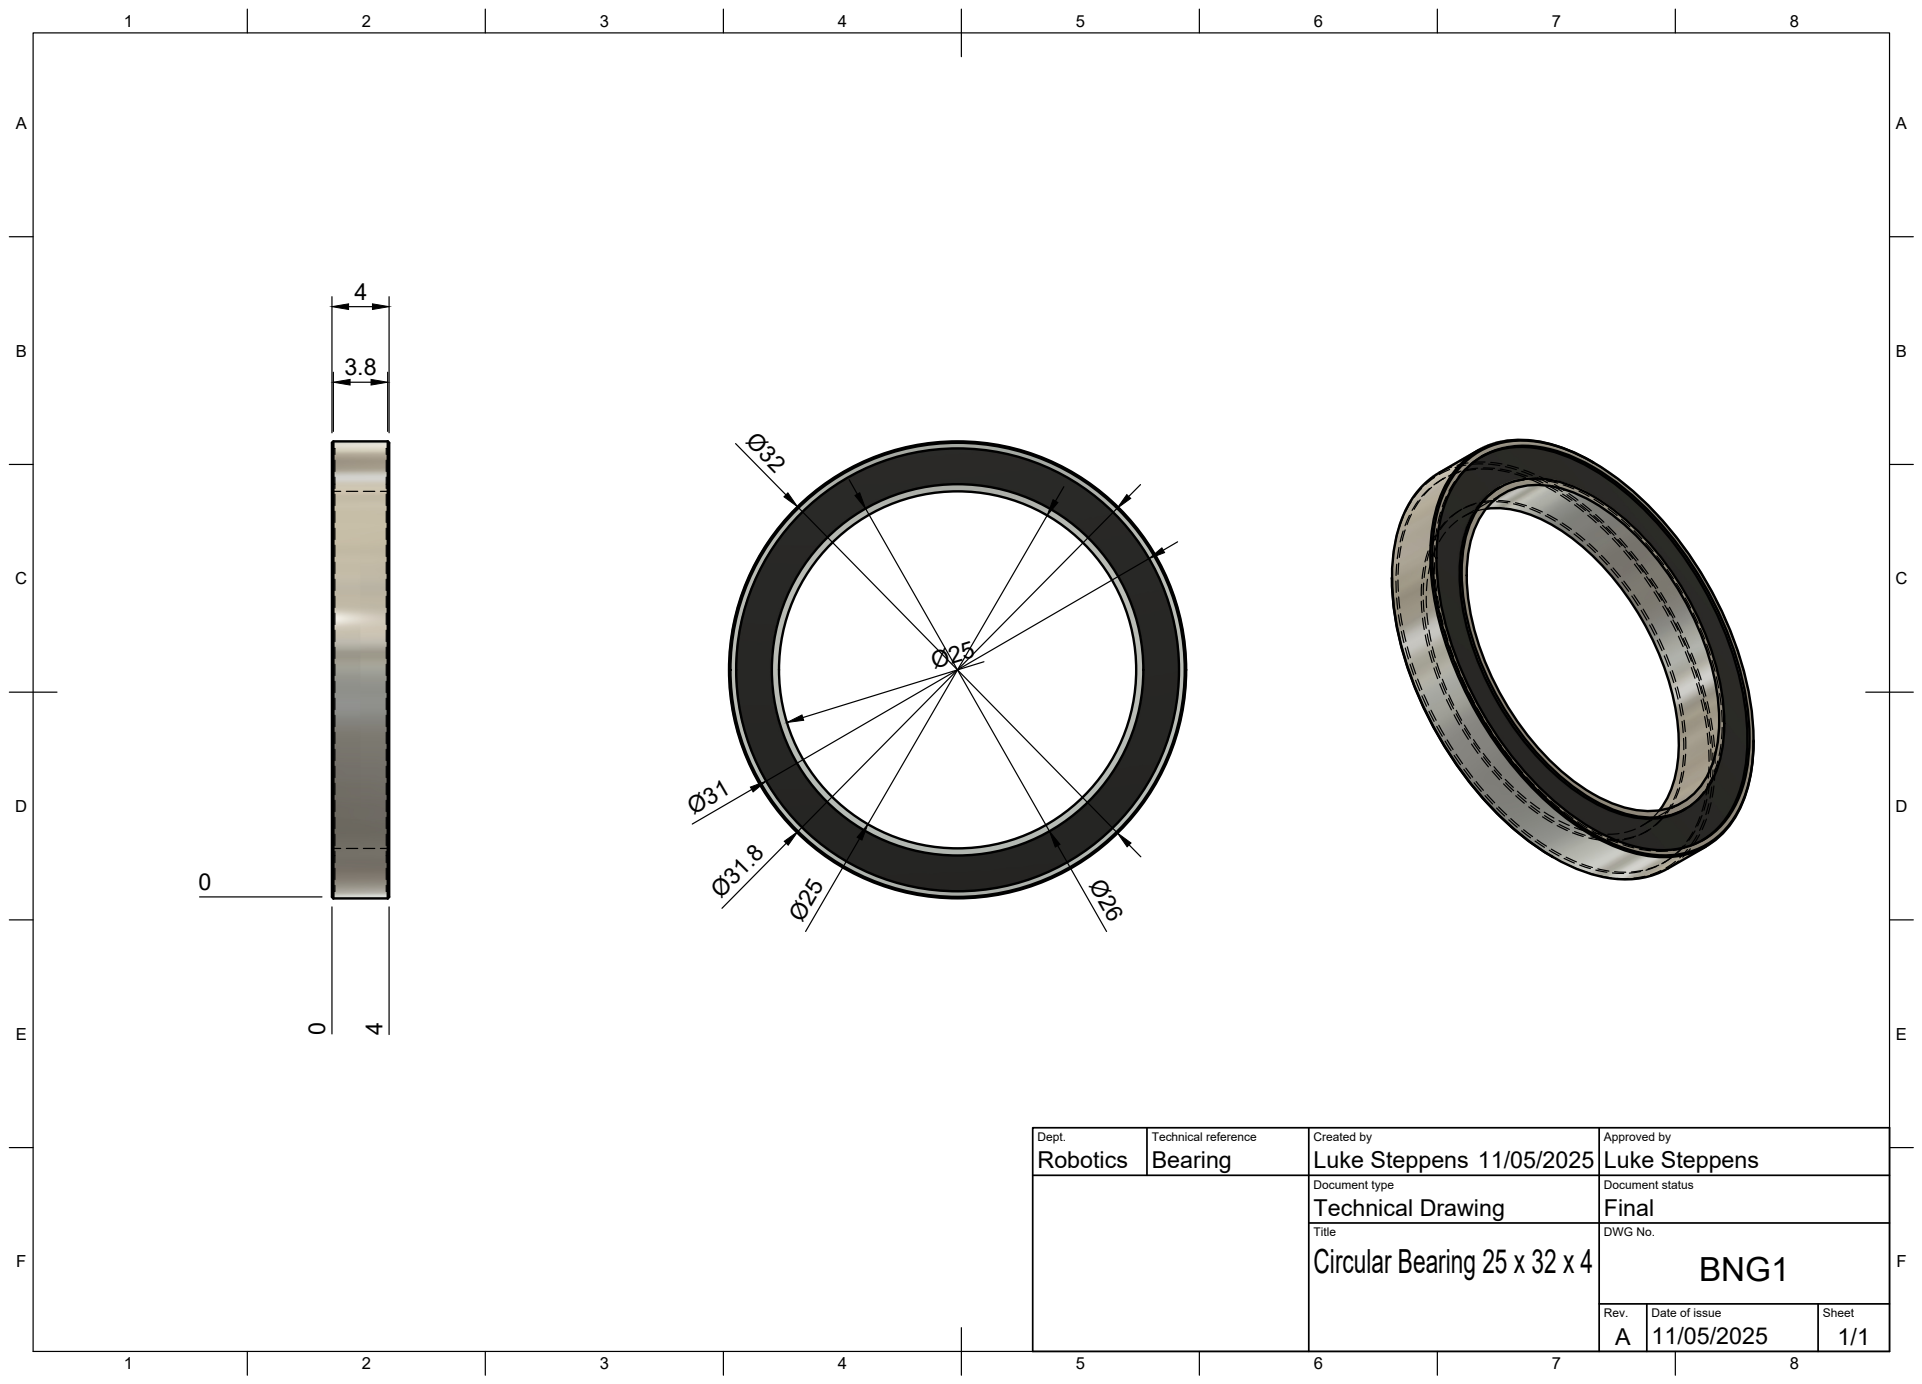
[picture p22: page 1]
Title; DWG No.; Rev.; Date of issue; Sheet; Circular Bearing 25 x 32 x 4; BNG1

Dept. Robotics | Technical reference Bearing | Created by Luke Steppens 11/05/2025 | Approved by Luke Steppens

Document type Technical Drawing | Document status Final

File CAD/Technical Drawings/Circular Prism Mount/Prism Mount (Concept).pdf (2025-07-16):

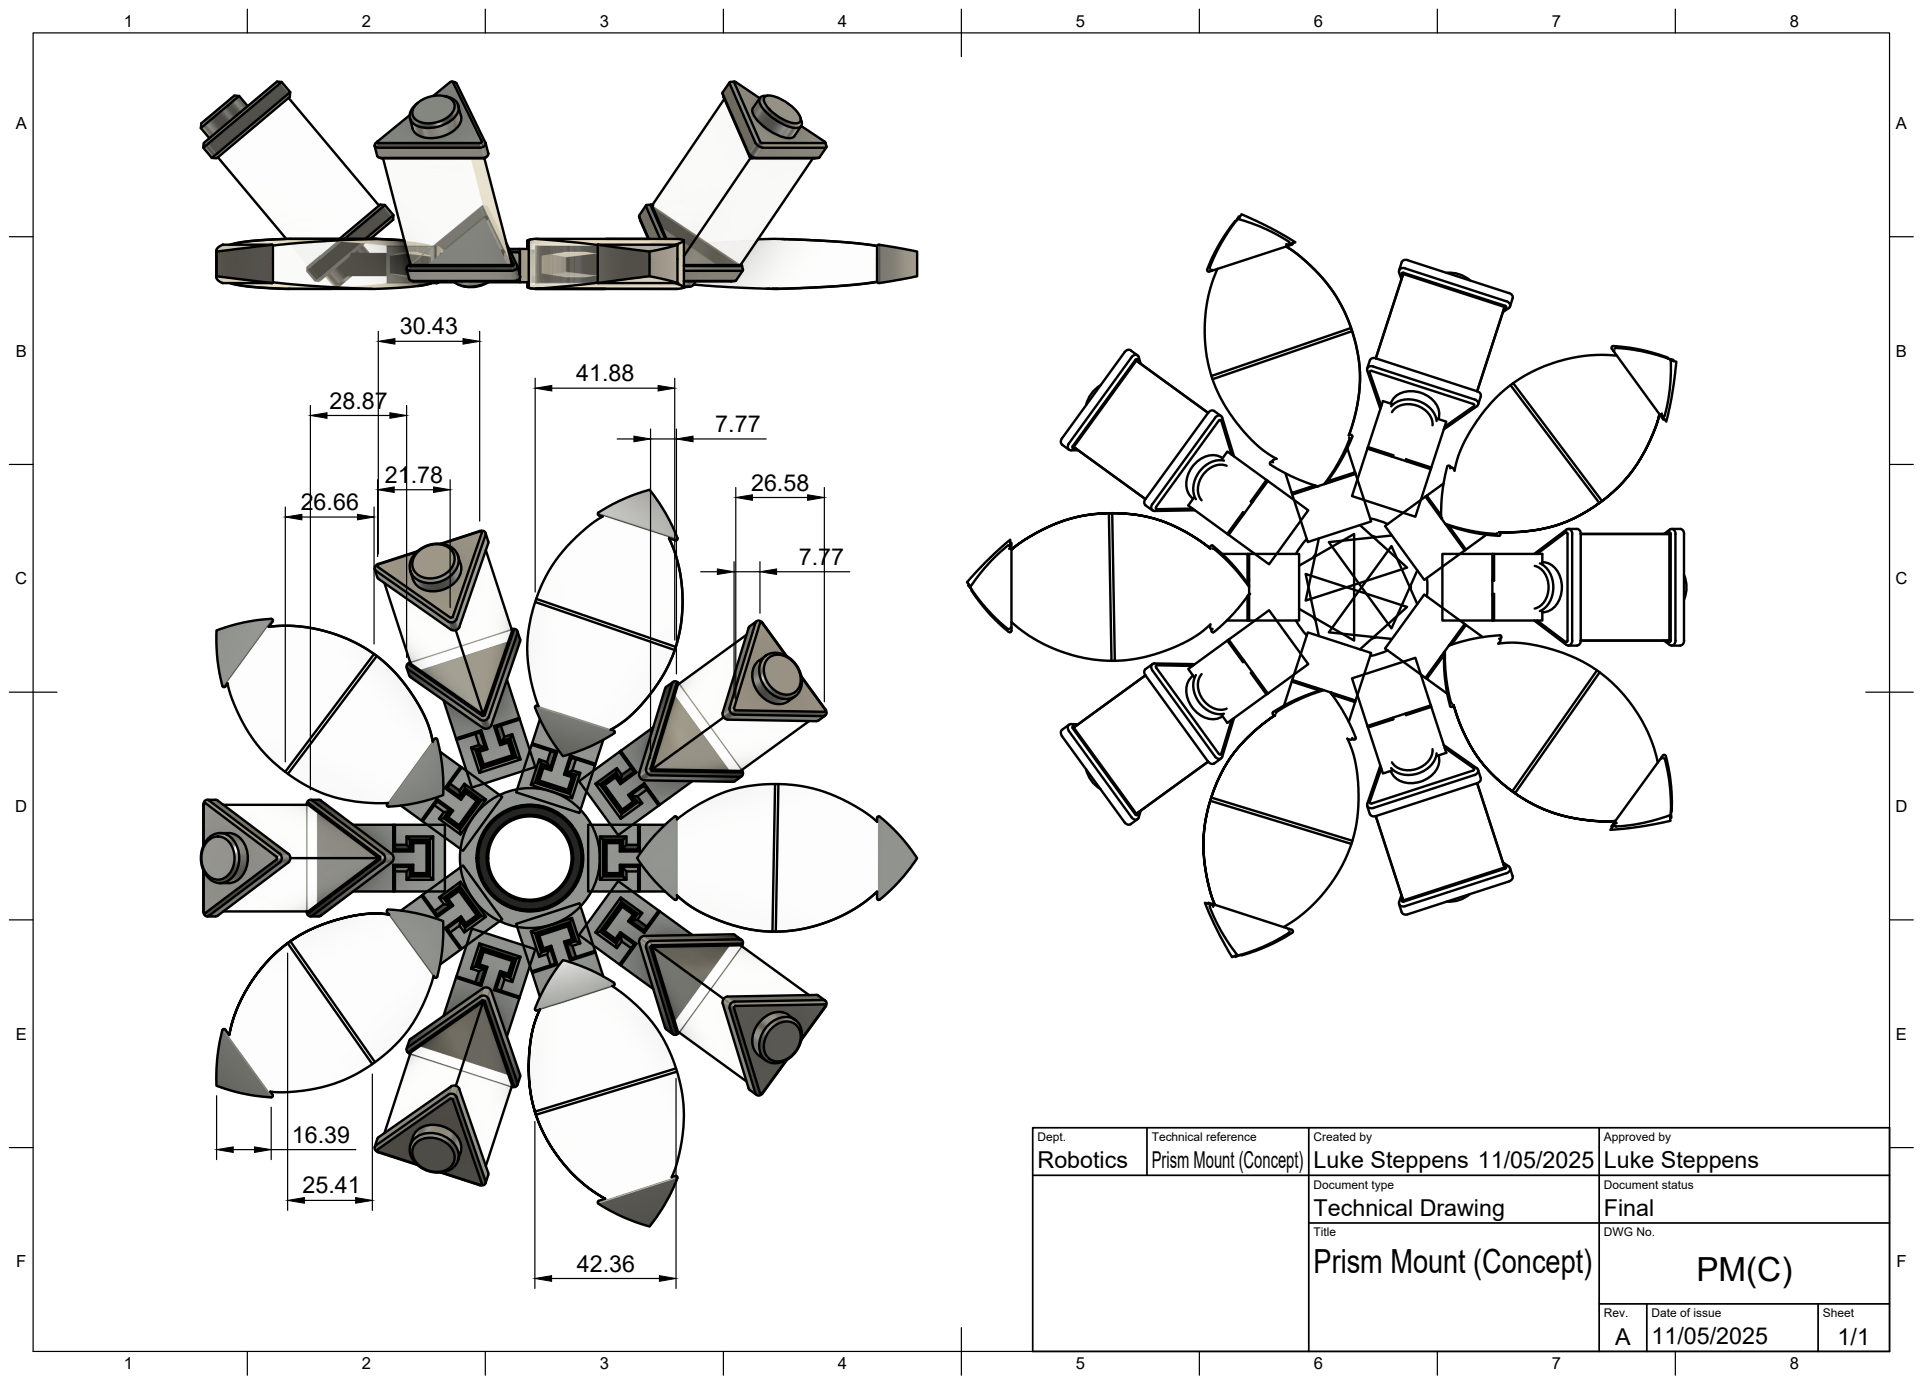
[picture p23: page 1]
Title; DWG No.; Rev.; Date of issue; Sheet; Prism Mount (Concept)

Dept. Robotics | Technical reference Prism Mount (Concept) | Created by Luke Steppens 11/05/2025 | Approved by Luke Steppens

Document type Technical Drawing | Document status Final

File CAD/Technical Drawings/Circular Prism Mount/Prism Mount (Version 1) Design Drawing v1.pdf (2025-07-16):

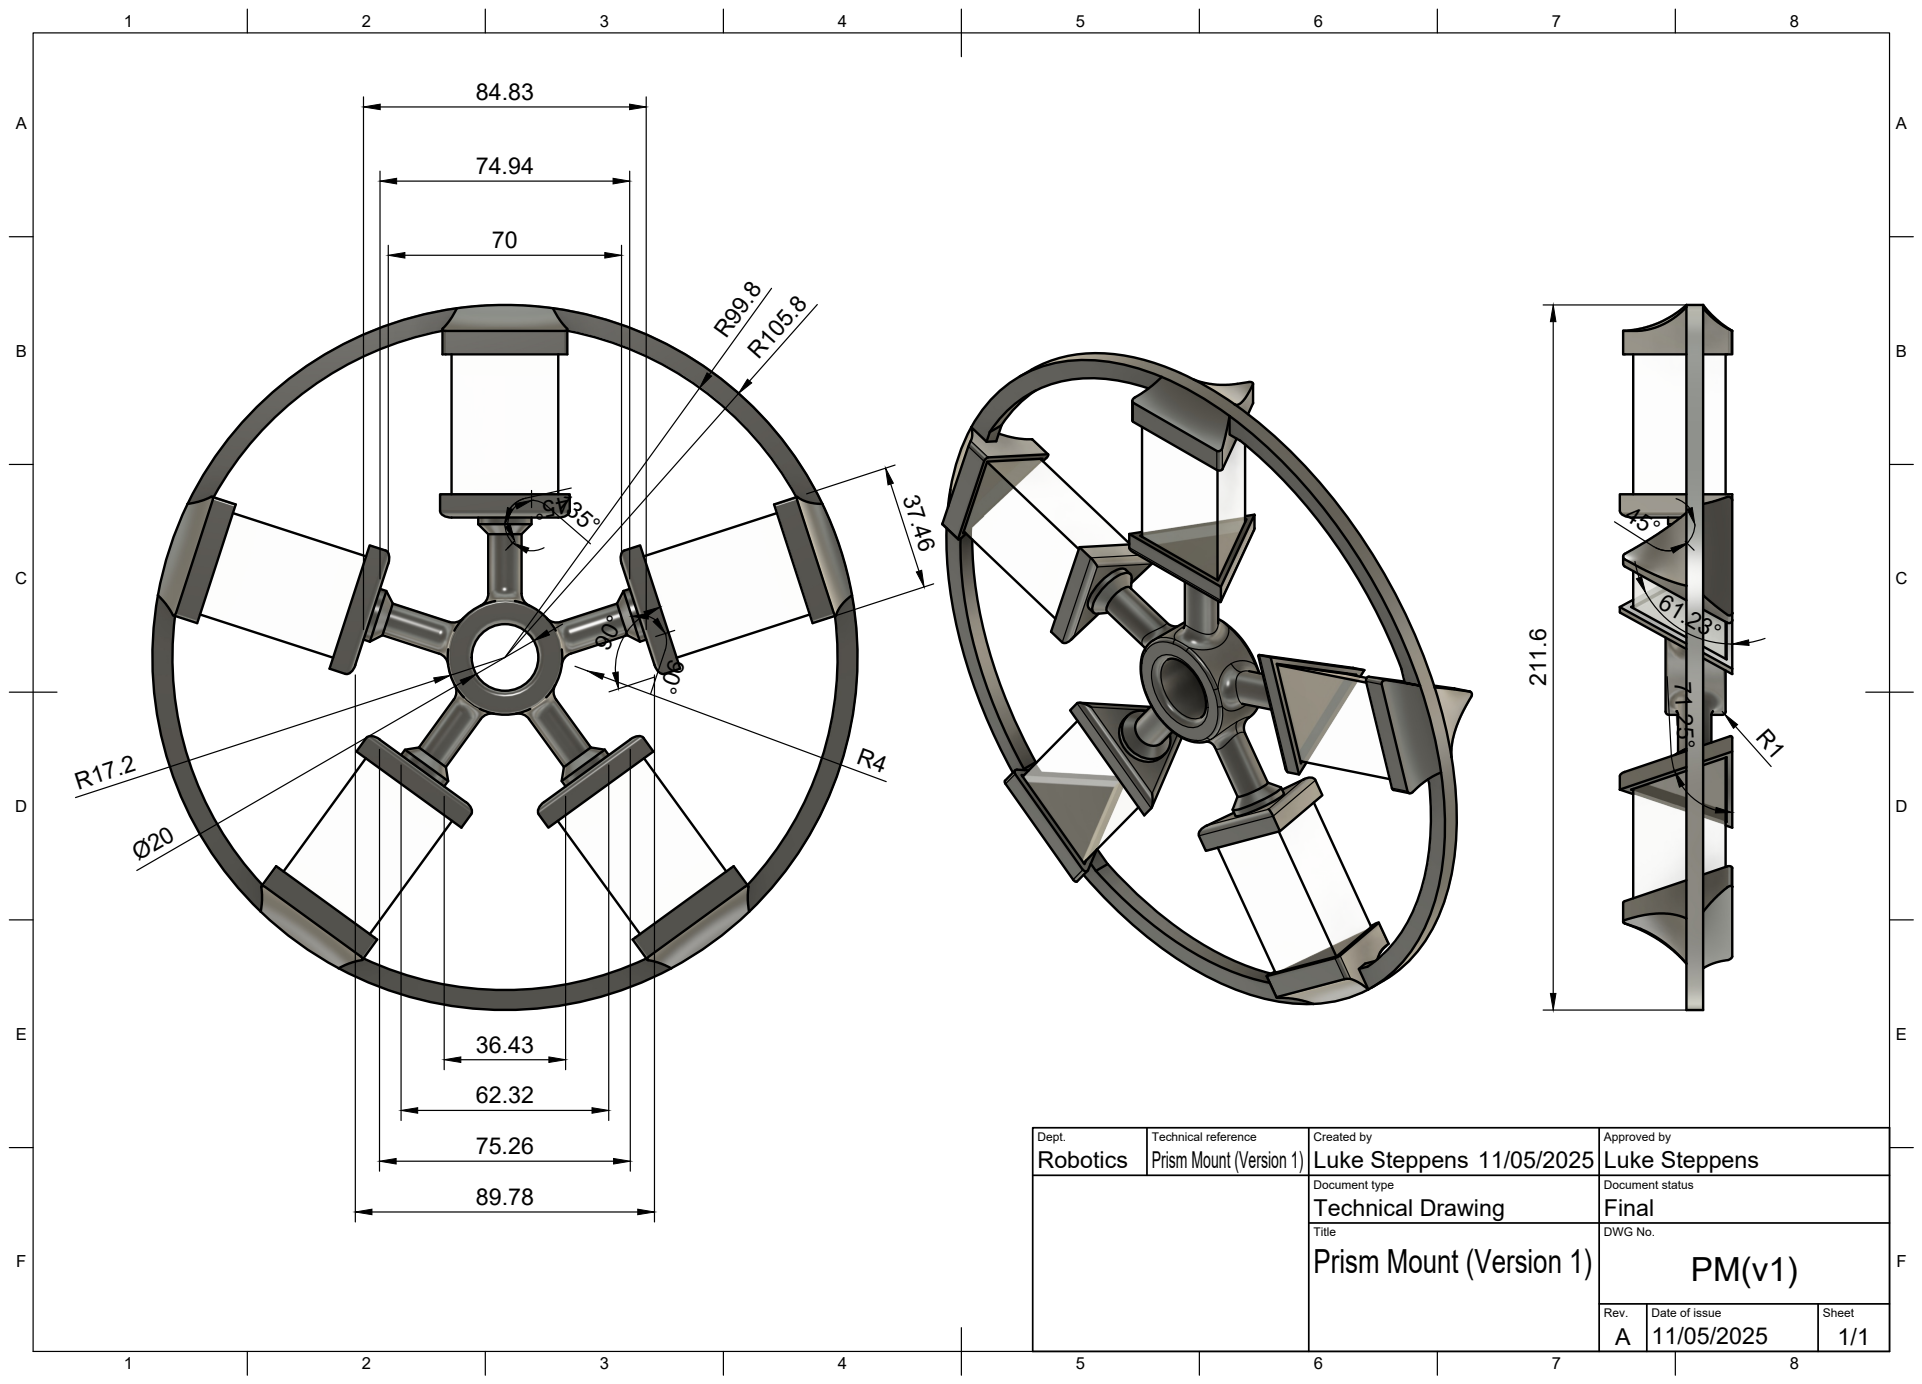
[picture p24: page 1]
Title; DWG No.; Rev.; Date of issue; Sheet; Prism Mount (Version 1)

Dept. Robotics | Technical reference Prism Mount (Version 1) | Created by Luke Steppens 11/05/2025 | Approved by Luke Steppens

Document type Technical Drawing | Document status Final

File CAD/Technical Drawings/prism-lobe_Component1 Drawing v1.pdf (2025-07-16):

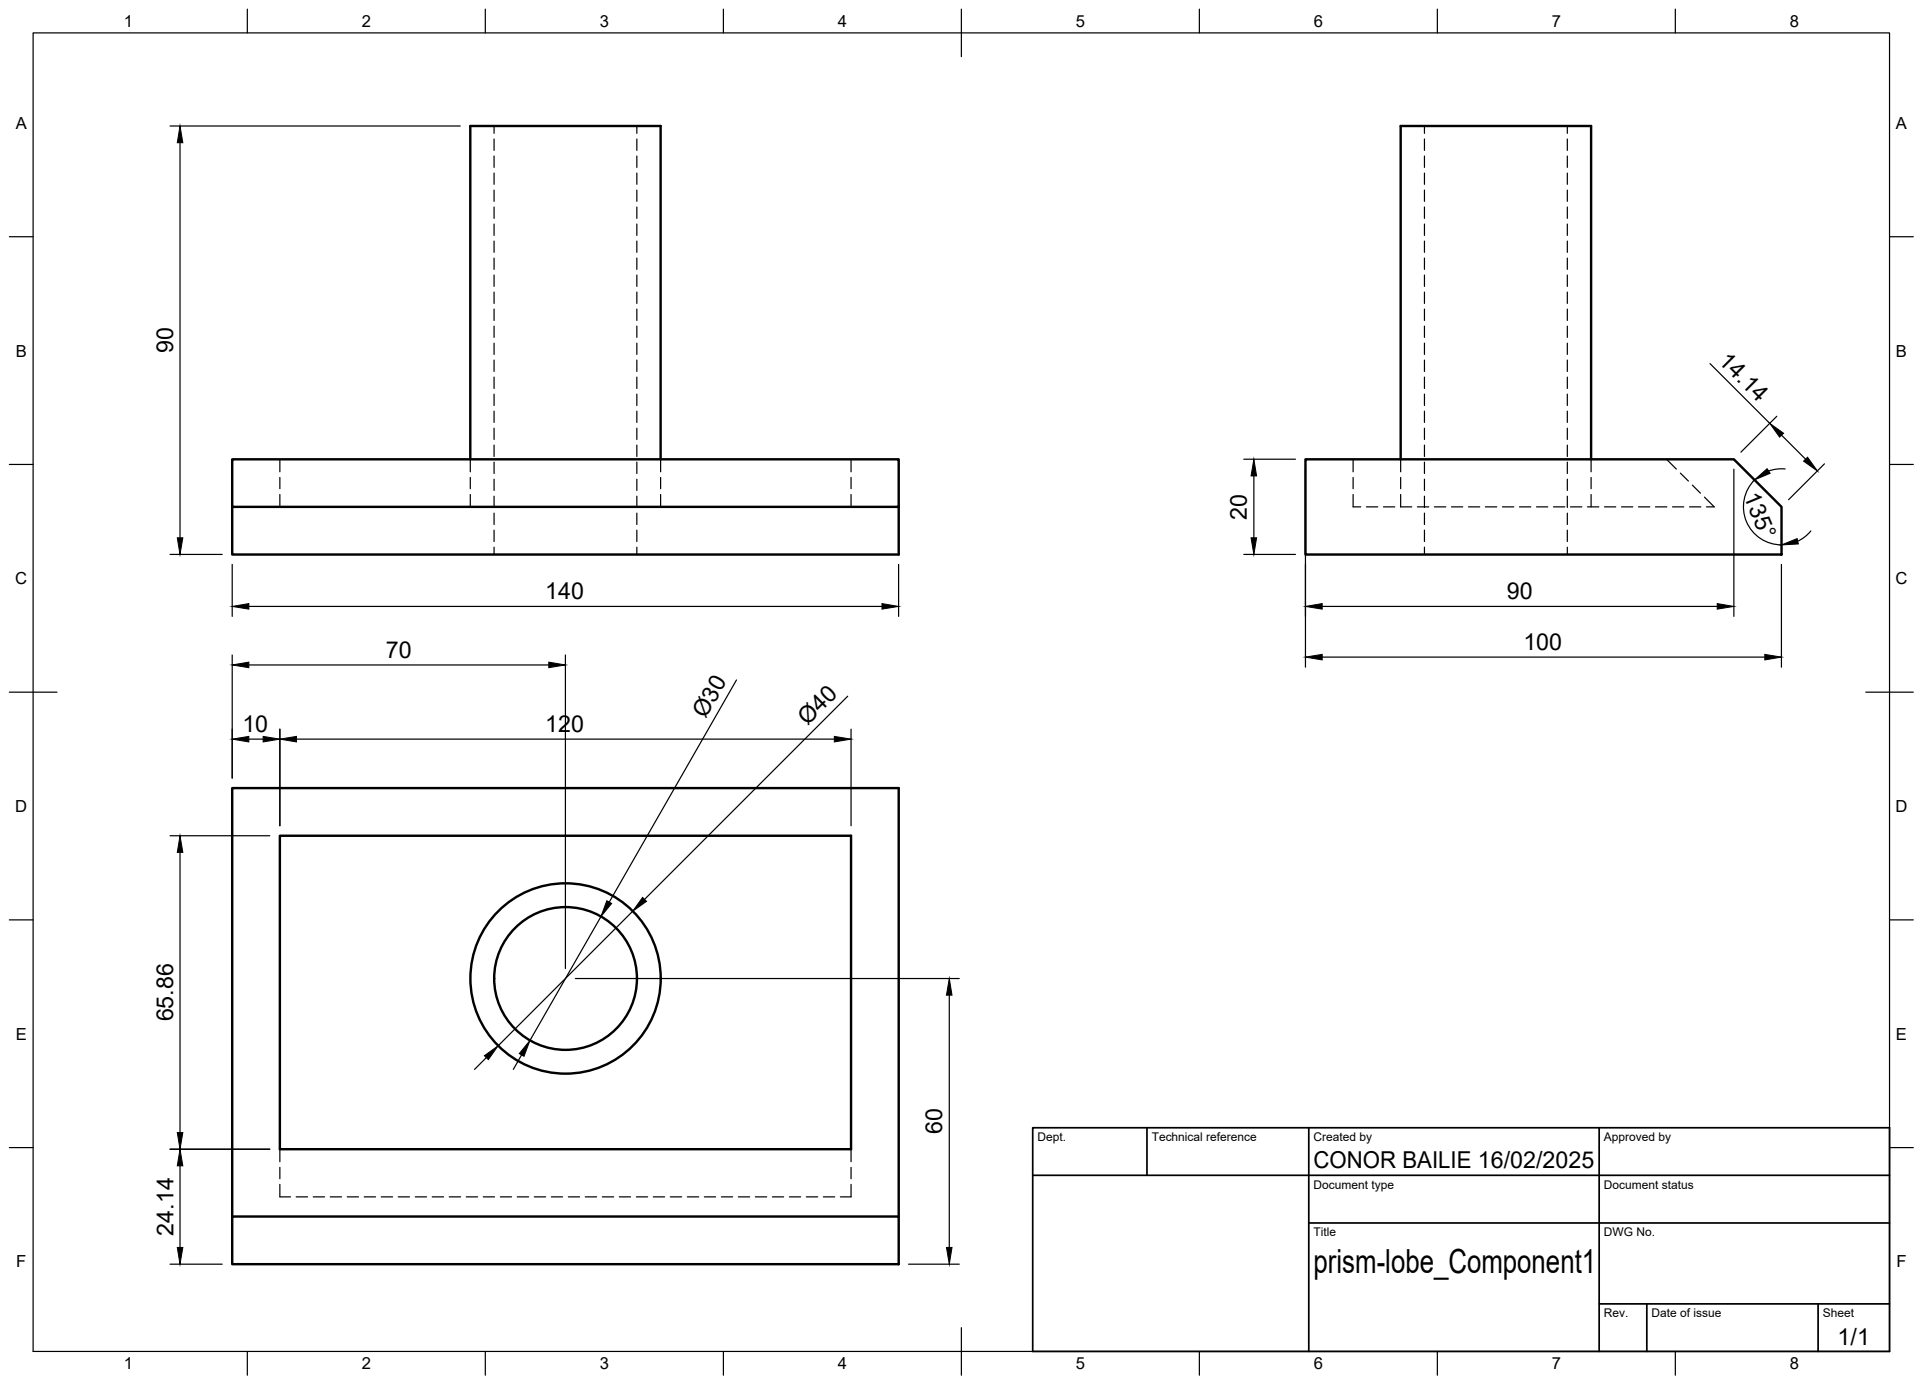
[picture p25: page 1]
Title; DWG No.; Rev.; Date of issue; Sheet

Dept. | Technical reference | Created by CONOR BAILIE 16/02/2025 | Approved by

Document type | Document status

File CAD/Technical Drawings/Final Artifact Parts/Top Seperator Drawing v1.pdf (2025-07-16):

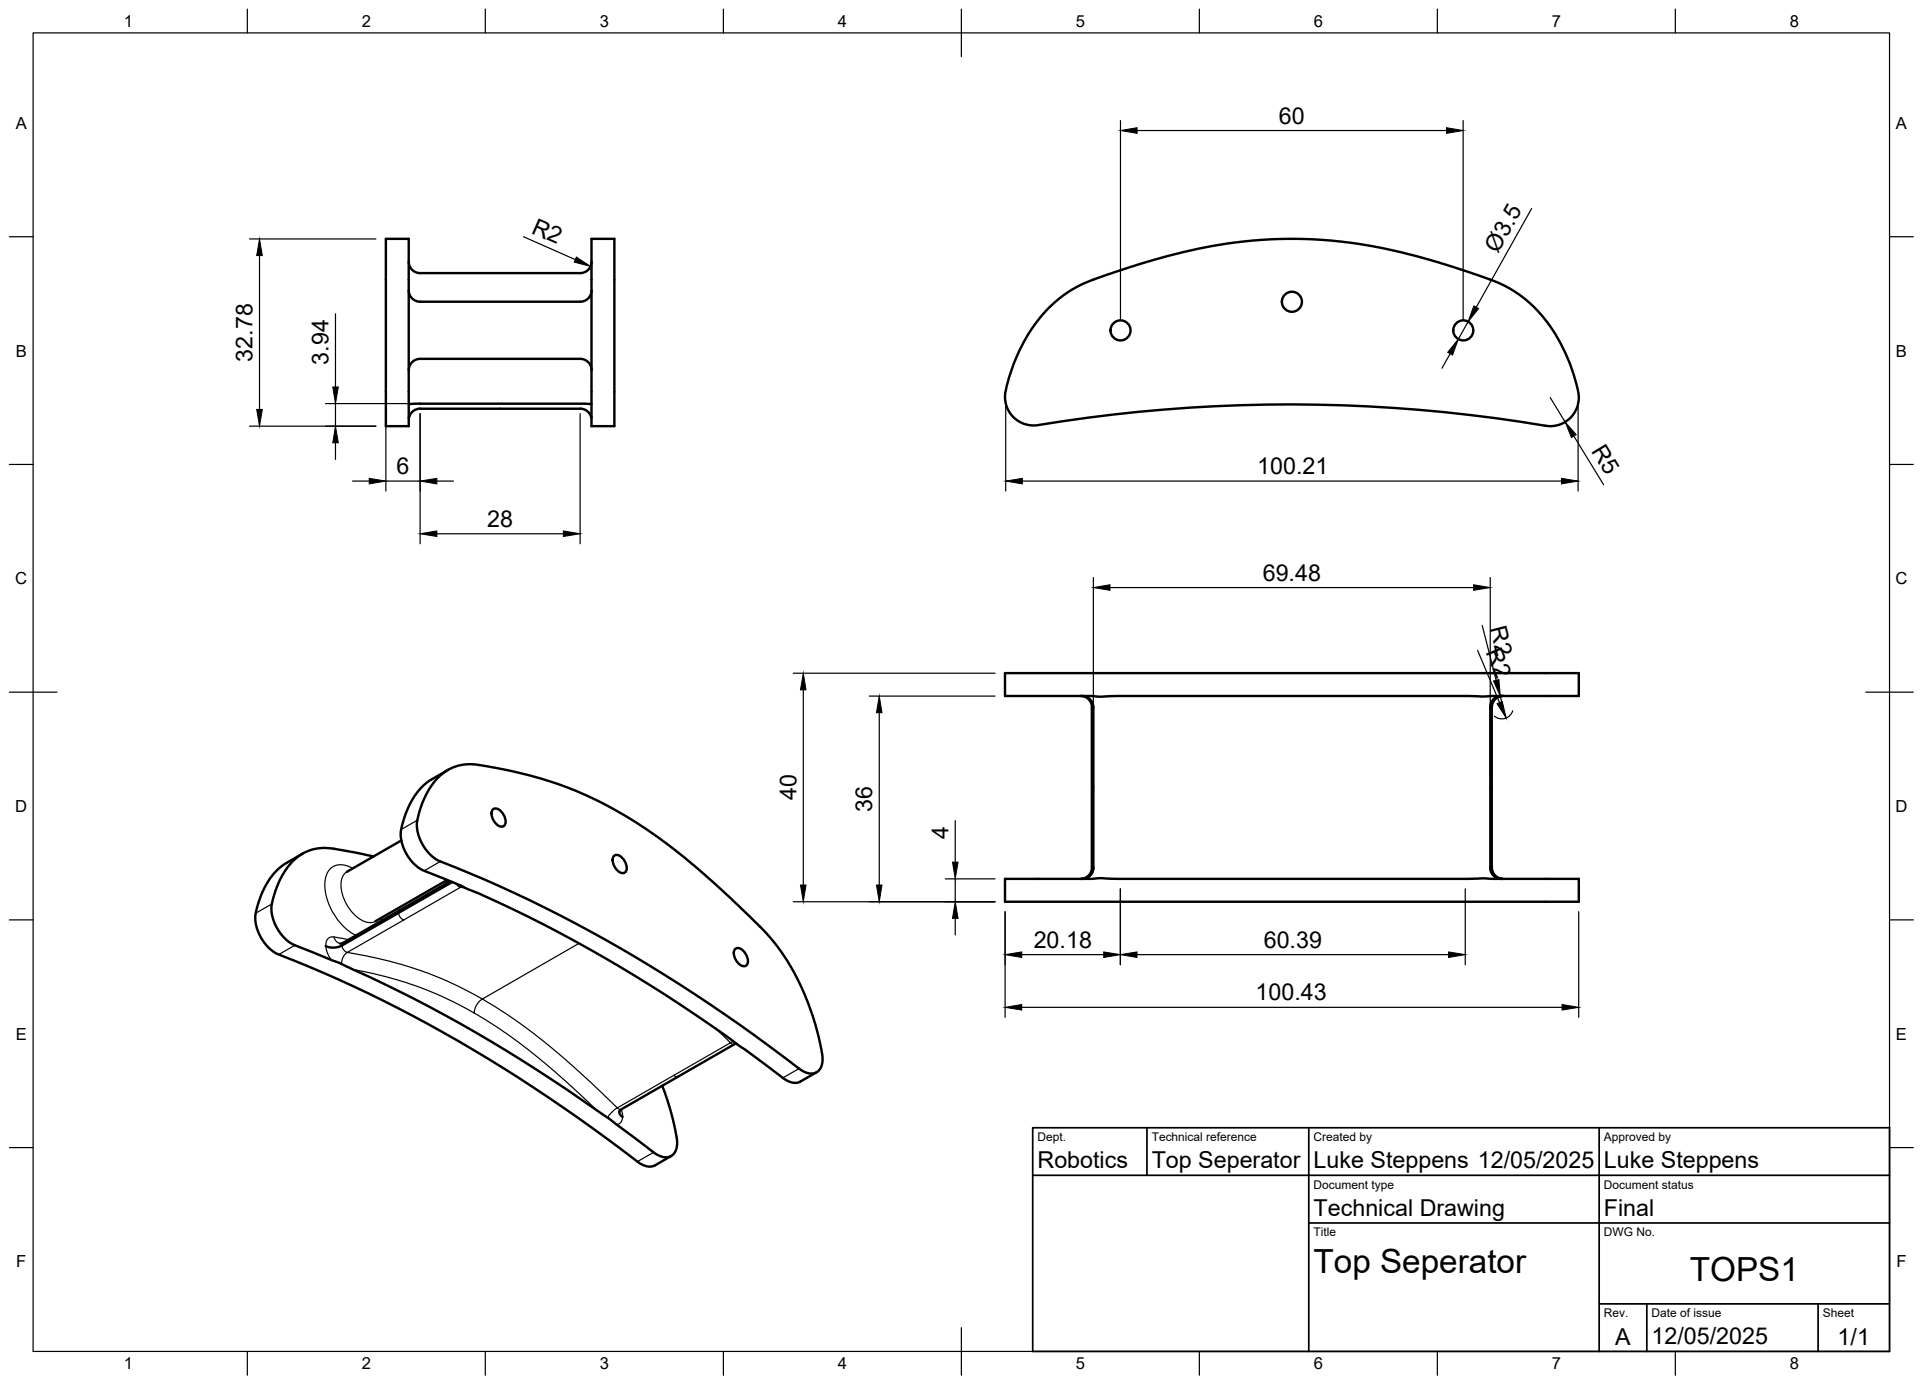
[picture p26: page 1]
Title; DWG No.; Rev.; Date of issue; Sheet; Top Seperator; TOPS1

Dept. Robotics | Technical reference Top Seperator | Created by Luke Steppens 12/05/2025 | Approved by Luke Steppens

Document type Technical Drawing | Document status Final

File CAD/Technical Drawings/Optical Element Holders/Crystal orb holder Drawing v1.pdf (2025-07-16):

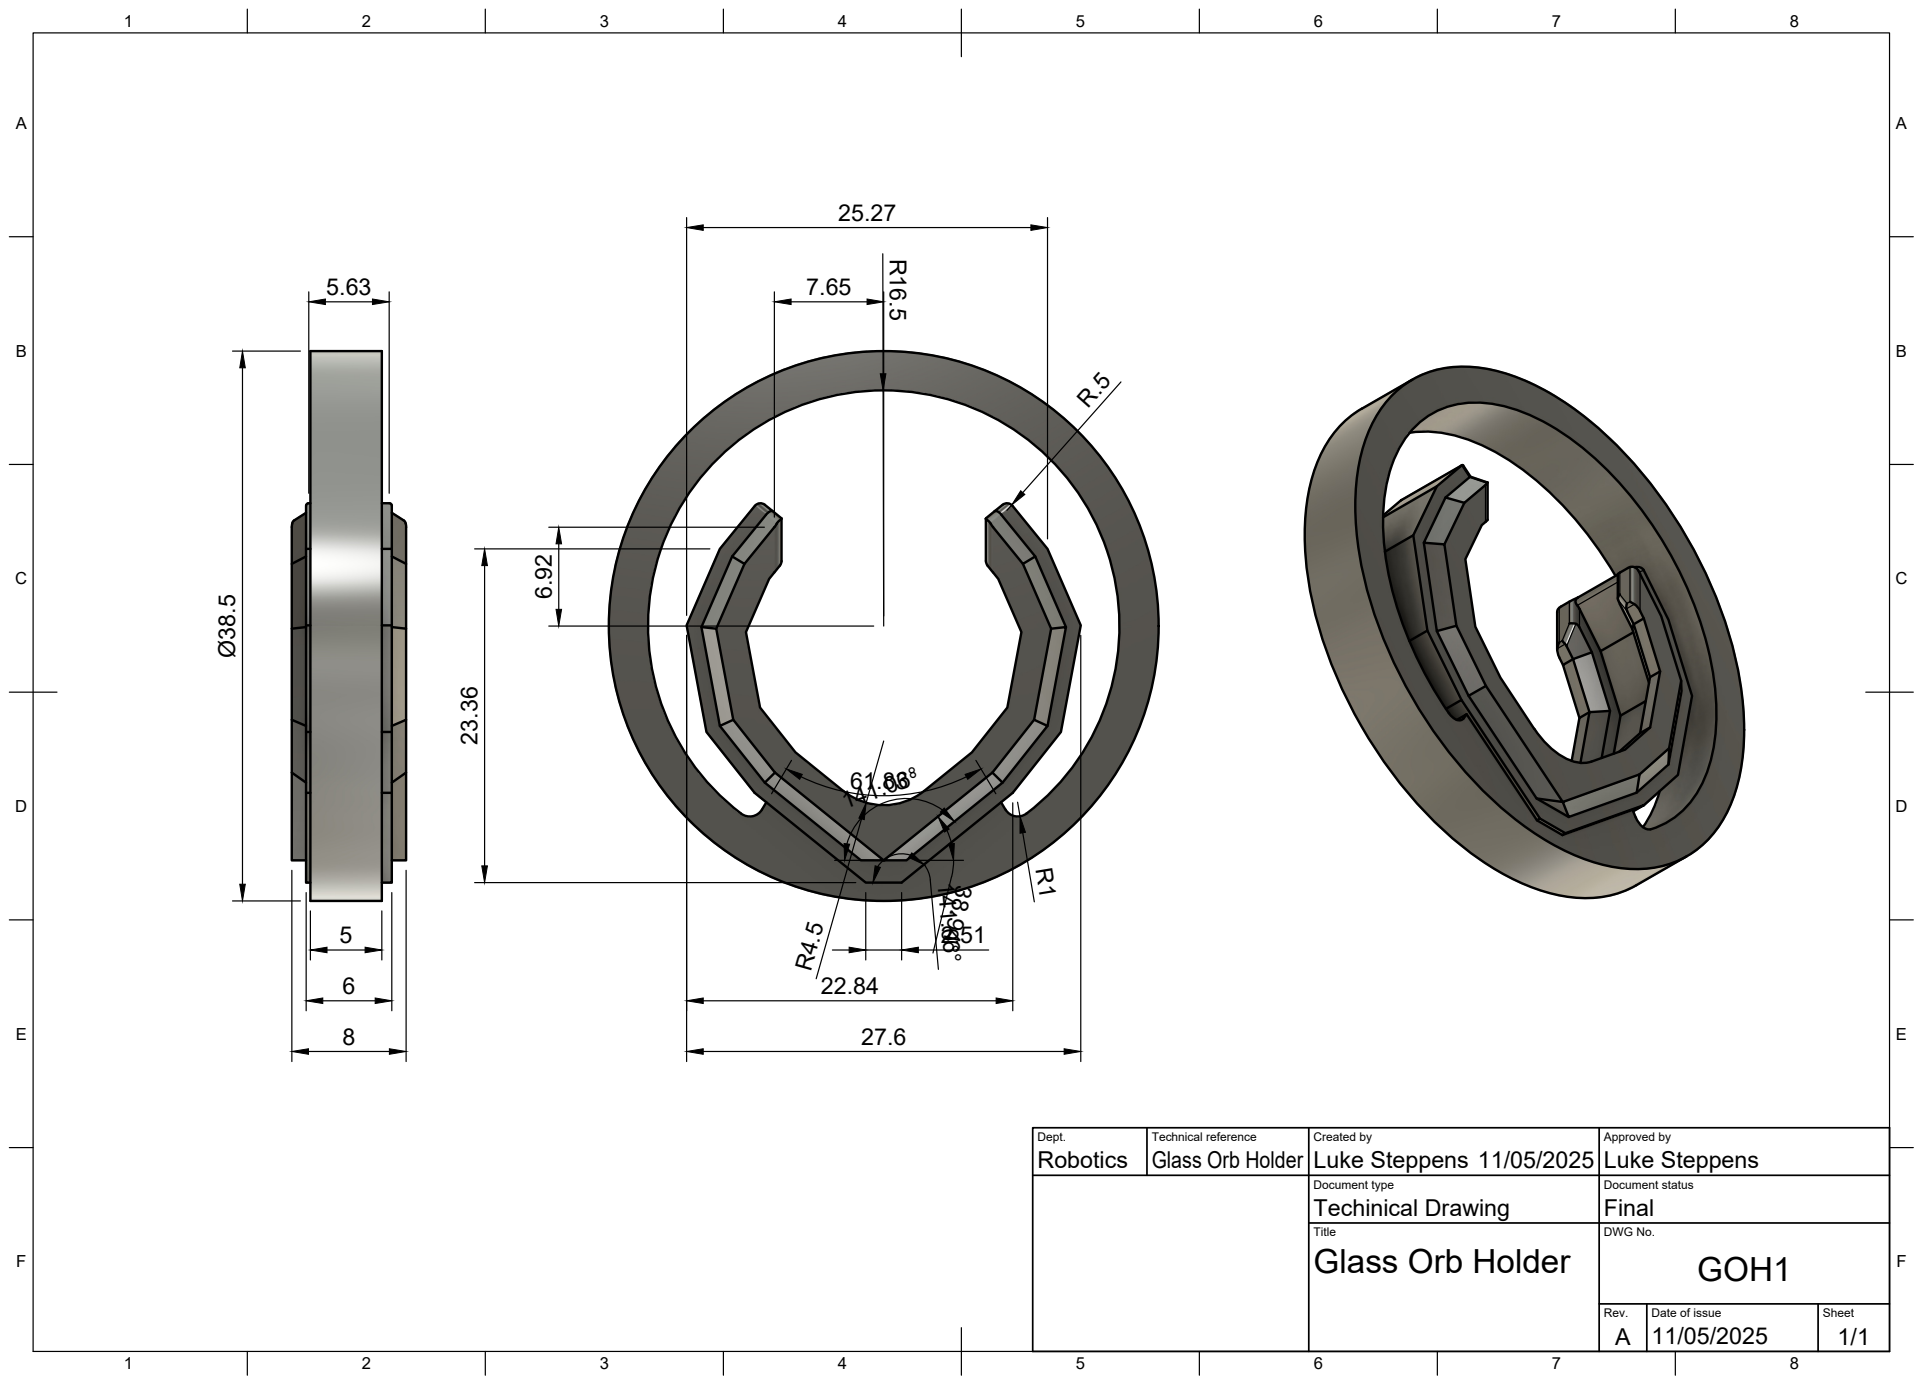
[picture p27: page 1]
Title; DWG No.; Rev.; Date of issue; Sheet; Glass Orb Holder; GOH1

Dept. Robotics | Technical reference Glass Orb Holder | Created by Luke Steppens 11/05/2025 | Approved by Luke Steppens

Document type Techinical Drawing | Document status Final

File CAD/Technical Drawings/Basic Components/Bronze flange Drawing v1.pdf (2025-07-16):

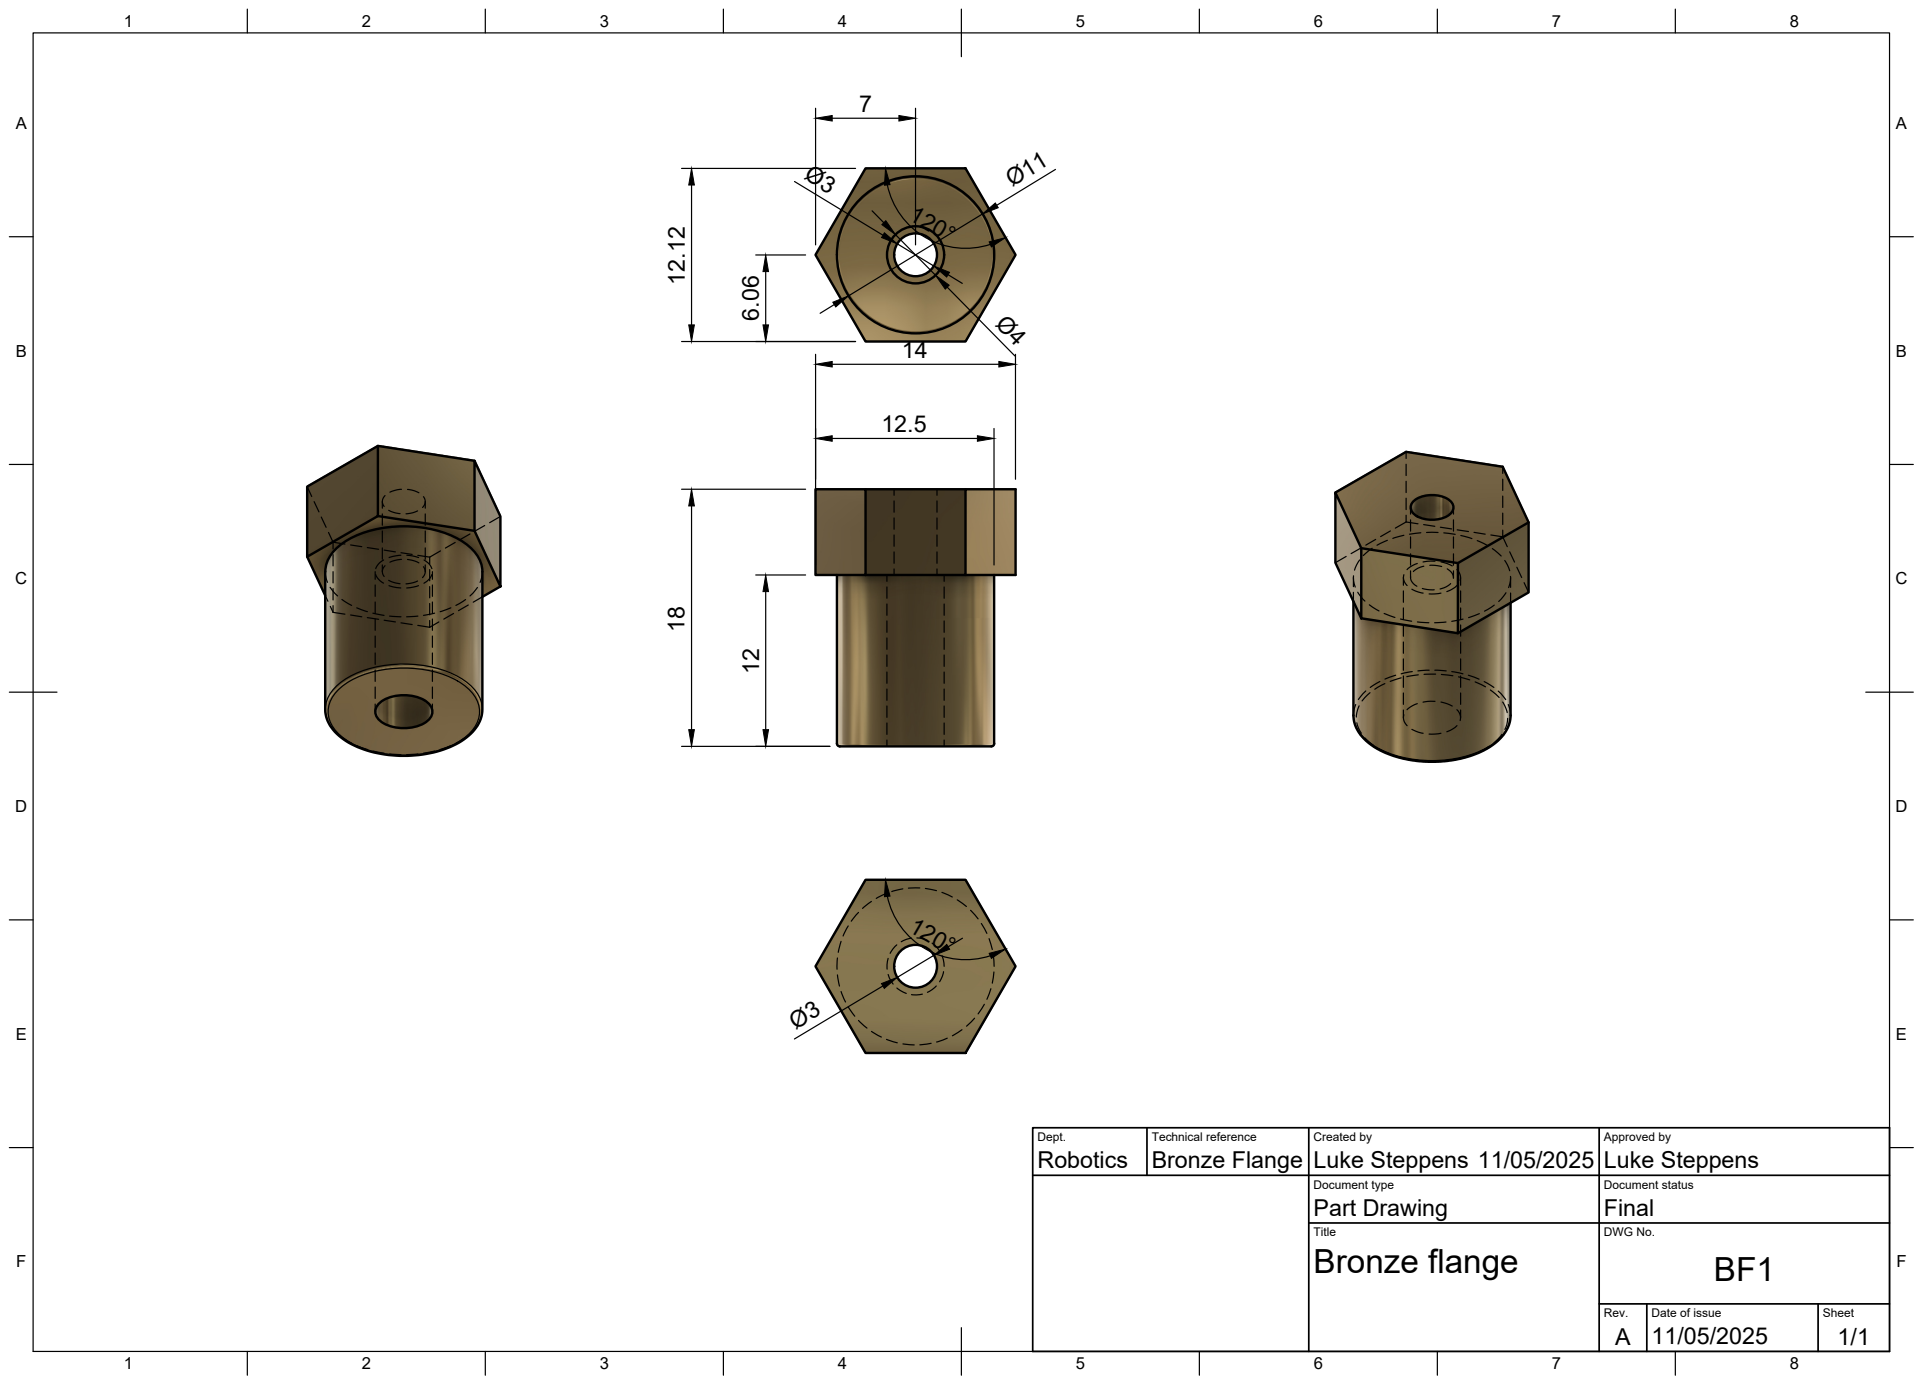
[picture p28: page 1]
Title; DWG No.; Rev.; Date of issue; Sheet; Bronze flange

Dept. Robotics | Technical reference Bronze Flange | Created by Luke Steppens 11/05/2025 | Approved by Luke Steppens

Document type Part Drawing | Document status Final

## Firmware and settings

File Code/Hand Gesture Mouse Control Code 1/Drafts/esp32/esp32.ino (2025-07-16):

#include "esp_camera.h"
#include <WiFi.h>

// Replace these with your network credentials
const char* ssid = "your_SSID";
const char* password = "your_PASSWORD";

// Camera configuration (for AI-Thinker ESP32-CAM)
camera_config_t config;

void startCameraServer();

void setup() {
  Serial.begin(115200);
  
  // Connect to Wi-Fi
  WiFi.begin(ssid, password);
  Serial.println("Connecting to WiFi...");
  
  while (WiFi.status() != WL_CONNECTED) {
    delay(1000);
    Serial.print(".");
  }
  
  // Wi-Fi connected
  Serial.println();
  Serial.println("Connected to WiFi");
  Serial.print("IP Address: ");
  Serial.println(WiFi.localIP());  // Print the ESP32-CAM's IP address
  
  // Camera configuration (adjust pins based on your ESP32-CAM model)
  config.ledc_channel = LEDC_CHANNEL_0;
  config.ledc_timer = LEDC_TIMER_0;
  config.pin_pwdn = 32;
  config.pin_reset = -1;  // No reset pin on this board
  config.pin_xclk = 0;
  config.pin_sscb_sda = 26;
  config.pin_sscb_scl = 27;
  config.pin_d7 = 36;
  config.pin_d6 = 39;
  config.pin_d5 = 34;
  config.pin_d4 = 35;
  config.pin_d3 = 21;
  config.pin_d2 = 19;
  config.pin_d1 = 18;
  config.pin_d0 = 5;
  config.pin_vsync = 25;
  config.pin_href = 23;
  config.pin_pclk = 22;
  
  // Camera settings
  config.xclk_freq_hz = 20000000;
  config.frame_size = FRAMESIZE_SVGA;
  config.jpeg_quality = 12;
  config.fb_count = 1;
  
  // Initialize the camera
  esp_err_t err = esp_camera_init(&config);
  if (err != ESP_OK) {
    Serial.println("Camera init failed");
    return;
  }
  
  // Start the camera server
  startCameraServer();
}

void loop() {
  delay(1);
}

// Start the camera server to stream video
void startCameraServer() {
  WiFiServer server(80);
  server.begin();
  Serial.println("HTTP server started");

  while (true) {
    WiFiClient client = server.available();
    
    if (!client) {
      return;
    }
    
    String request = client.readStringUntil('\r');
    client.flush();
    
    // Stream video (MJPEG format)
    if (request.indexOf("GET /stream") >= 0) {
      client.println("HTTP/1.1 200 OK");
      client.println("Content-Type: multipart/x-mixed-replace; boundary=frame");
      client.println();
      
      while (true) {
        // Capture a frame from the camera
        camera_fb_t *fb = esp_camera_fb_get();
        
        if (!fb) {
          Serial.println("Failed to capture image");
          return;
        }
        
        client.println("--frame");
        client.println("Content-Type: image/jpeg");
        client.println("Content-Length: " + String(fb->len));
        client.println();
        
        // Send the image data
        client.write(fb->buf, fb->len);
        
        client.println();
        esp_camera_fb_return(fb);  // Return the frame buffer to be reused
        
        delay(100);  // Limit the frame rate
      }
    }
    
    client.stop();
  }
}

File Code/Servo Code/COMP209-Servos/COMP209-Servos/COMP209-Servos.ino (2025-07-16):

#include "Servo.h"

Servo frontServo;
Servo backServo;
Servo leftServo;
Servo rightServo;


void setup() {
  // put your setup code here, to run once:
  Serial.begin(9600);
  frontServo.attach(6);
  backServo.attach(7);
  leftServo.attach(8);
  rightServo.attach(9);
}

void loop() {
  // put your main code here, to run repeatedly:
  frontServo.write(90); // Servos work from 0 to 360 degrees.
  backServo.write(180); // Servos work from 0 to 360 degrees.
  leftServo.write(270); // Servos work from 0 to 360 degrees.
  rightServo.write(360); // Servos work from 0 to 360 degrees.

  delay(1000);  

}
